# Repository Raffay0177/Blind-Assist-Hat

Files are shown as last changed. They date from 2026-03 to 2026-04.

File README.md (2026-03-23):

# 🧢 Blind Assist Hat (BAH)

Welcome to the **Blind Assist Hat** project! This project aims to create an affordable, smart wearable device designed to help visually impaired individuals navigate their surroundings, read text, and understand the environment around them.

The system uses a combination of ultrasonic sensors, a Raspberry Pi Camera, and OpenAI's GPT-4o Vision API to act as a pair of "digital eyes," controlled entirely via a tactile 4-button wrist pad.

---

## 🌟 Key Features

1. **Obstacle Detection:** Ultrasonic sensors on the front, left, and right gently warn the user via dynamic audio beeps if they are getting too close to an object.
2. **Scene Description:** The AI looks through the camera and verbally describes what is in front of the user (e.g., *"There is a park bench and a tree ahead."*).
3. **Text Reading:** Identifies and reads street signs, documents, or labels out loud.
4. **Navigation Mode:** Toggles continuous proximity sensing.

---

## 🛠️ System Architecture

### 1. The 'Brain' (Raspberry Pi)
A Raspberry Pi acts as the central hub, processing all hardware interrupts and routing API calls.

### 2. The 'Eyes' (Sensors & Camera)
- **Camera (CSI Port):** Captures high-res frames for the Vision AI.
- **Ultrasonics (HC-SR04):** Measures physical distances. *(Warning: Requires a voltage divider for the Echo pins to protect the Pi's 3.3V GPIO).*

### 3. The 'Remote' (Wrist Pad)
A 4-button tactile interface worn on the wrist:
- **Button 1:** Describe the scene.
- **Button 2:** Read text/signs.
- **Button 3:** Toggle Navigation Mode (Ultrasonic warnings).
- **Button 4:** Repeat the last spoken output.

### 4. The 'Voice' (Speaker)
Native synthesized speech (Text-to-Speech) pushed directly through the Pi's 3.5mm Jack or HDMI port. No external buzzer required!

---

## 📁 Project Structure

```text
BDH/
├── ai/                 # OpenAI Vision API routing and TTS handlers
├── config/             # Centralized settings and GPIO pin mappings
├── core/               # Main application loop, state handling, and button dispatchers
├── hardware/           # Hardware schematics, 3D printable STL/SCAD models
├── input/              # GPIO button interrupt logic
├── sensors/            # Ultrasonic distance algorithms and picamera2 wrappers
├── tests/              # End-to-end workflow suite for PC testing
├── .env.example        # Environment variable template
├── install.sh          # One-shot Raspberry Pi setup script
└── requirements.txt    # Current Python dependencies
```

---

## 🚀 Getting Started

If you are a builder or technician setting this up on a Raspberry Pi, follow these steps:

### 1. Hardware Assembly
Before booting, refer to the wiring guides in the `hardware/schematics/` folder. 
> **Important:** Follow `hardware/schematics/gpio_wiring.md` closely to ensure you don't fry your Raspberry Pi using the 5V ultrasonic sensors!

### 2. Software Installation
Run the one-shot setup script to install all system dependencies (like `espeak` and `libcamera`) and generate the Python virtual environment:
```bash
bash install.sh
```

### 3. Configuration
Copy the provided `.env.example` file to `.env`:
```bash
cp .env.example .env
```
Open `.env` and configure your API keys:
```env
OPENAI_API_KEY=sk-your-openai-api-key-here
OBSTACLE_WARN_DISTANCE_CM=100
```
*(You can also adjust the max warning distance for ultrasonic navigation mode here).*

### 4. Running the System
Activate your environment and start the core loop:
```bash
source venv/bin/activate
python -m core.main
```

---

## 💻 Cross-Platform Testing (Windows/Mac)
Don't have a Raspberry Pi handy? The codebase is designed to safely degrade when missing physical hardware.
You can run `python tests/test_end_to_end.py` on your Windows/Mac PC to simulate button presses and test the flow logs!

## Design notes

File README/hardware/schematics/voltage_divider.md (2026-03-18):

# ⚡ The Voltage Divider (Translating Voltages Safely)

## Why do we need this? (The Simple Explanation)

In the Blind Assist Hat, our distance sensors (the Ultrasonic HC-SR04 sensors) run on **5 Volts** of electricity.
However, the "Brain" (our Raspberry Pi computer) is very sensitive and can only handle **3.3 Volts**.

If the 5-volt sensor shouts its signal directly into the 3.3-volt brain, it will cause permanent electrical damage to the Raspberry Pi!

**Think of it like this:** The sensor is a megaphone, and the Raspberry Pi has very sensitive ears. We need to put a muffler between them so the Pi can hear the signal safely without getting hurt.

## How it works
To safely connect them, we use a simple **Voltage Divider**. This is just two tiny electrical resistors placed in the wire path. They "divide" the electrical pressure, scaling the 5V signal safely down to ~3.3V.

### How to build it for the "Echo" wire
*(You must do this for the 'Echo' wire of ALL THREE front/left/right sensors)*

1. Take the **Echo** wire coming directly from the Sensor.
2. Add a `1kΩ resistor` (Resistor 1).
3. After Resistor 1, the wire splits into two paths:
   - **Path A** goes straight into the correct Raspberry Pi GPIO Pin (e.g., Pin 24 for the front sensor).
   - **Path B** goes through a `2kΩ resistor` (Resistor 2) and then connects to the **Ground (GND)**.

By simply running the electricity through these resistors in a fork shape, the voltage drops to a safe level, and the Raspberry Pi reads the distance signal perfectly!

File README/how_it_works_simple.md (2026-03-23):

# 🎩 How the Hat Works (Explained for a 2-Year-Old!)

Imagine you have a magical talking hat! 🧙‍♂️✨

Here is what the hat has inside it:

### 1. The Brain 🧠 (Raspberry Pi)
Inside the hat is a tiny, smart computer. It thinks very fast and tells all the other parts what to do! It is the boss of the hat.

### 2. The Eyes 👀 (Camera & Sensors)
- **The Camera** looks at what is in front of you. It can see trees, people, and read signs!
- **The Bat Ears (Sensors)** send out invisible sound waves that bounce off walls. If a wall is too close, the ears hear the echo and secretly tell the Brain!

### 3. The Voice 🗣️ (Speaker)
The hat can talk to you! If the bat ears hear a wall getting super close, the hat uses its Voice to go *"BEEP BEEP!"* so you don't bump your head. If the camera sees a dog, the hat uses its Voice to say *"I see a dog!"*

### 4. The Magic Buttons 🖲️ (Wrist Pad)
You wear a cool bracelet with 4 big buttons. You press a button to ask the hat a question!
- **Press Button 1:** "Hat, what do you see right now?"
- **Press Button 2:** "Hat, can you read that sign for me?"
- **Press Button 3:** "Hat, turn on the bat ears so I don't bump into things!"
- **Press Button 4:** "Hat, can you say that one more time?"

---

## 🔄 How They Play Together!
When you press a **Magic Button**, the **Brain** wakes up! It asks the **Eyes** to take a quick peek. The Brain thinks about what the Eyes saw, and then it uses the **Voice** to whisper in your ear so you can walk safely and happily! 🚶‍♂️🎉

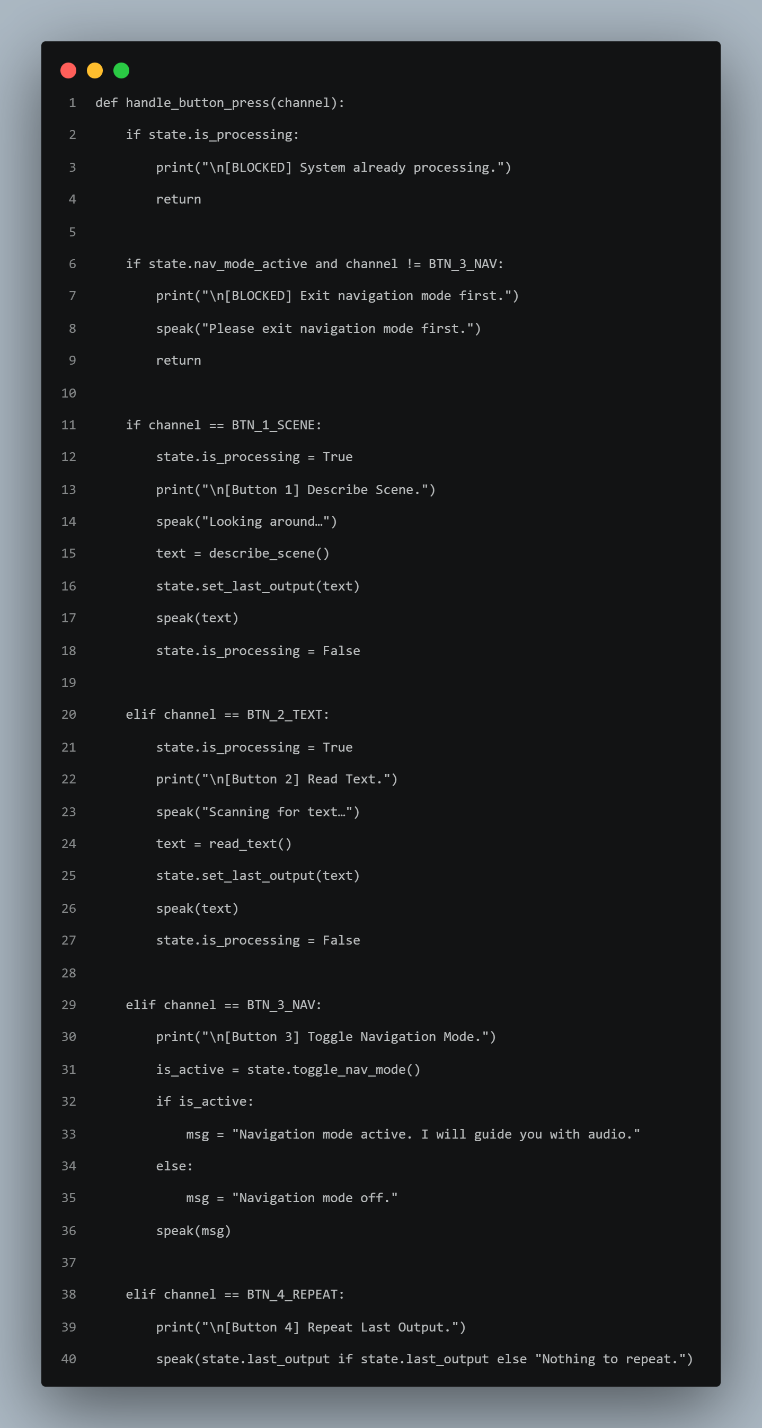
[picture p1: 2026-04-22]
README/hardware/schematics/Code Pictures/button_logic.png

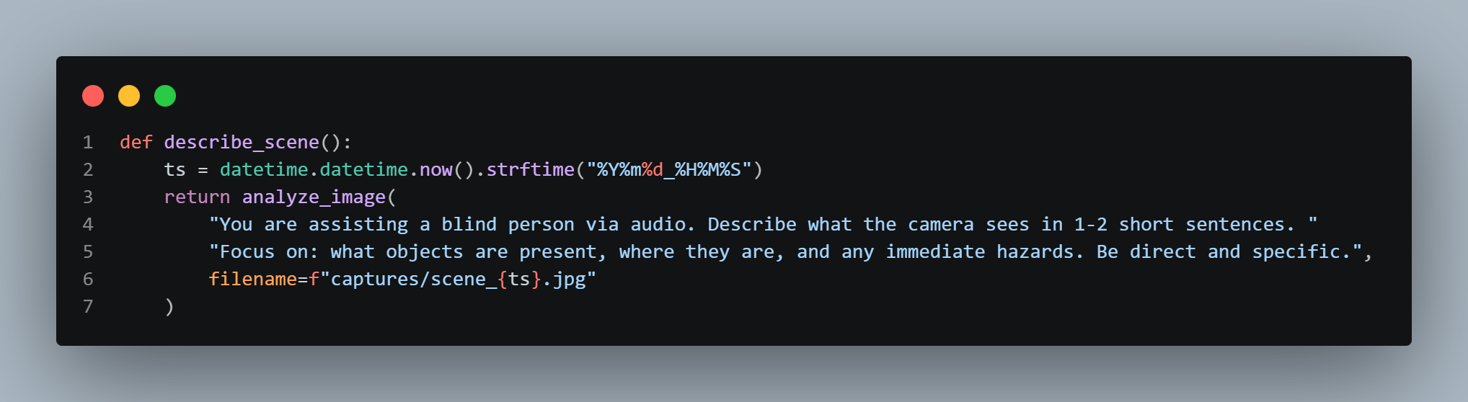
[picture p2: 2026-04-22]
README/hardware/schematics/Code Pictures/describe_scene.png

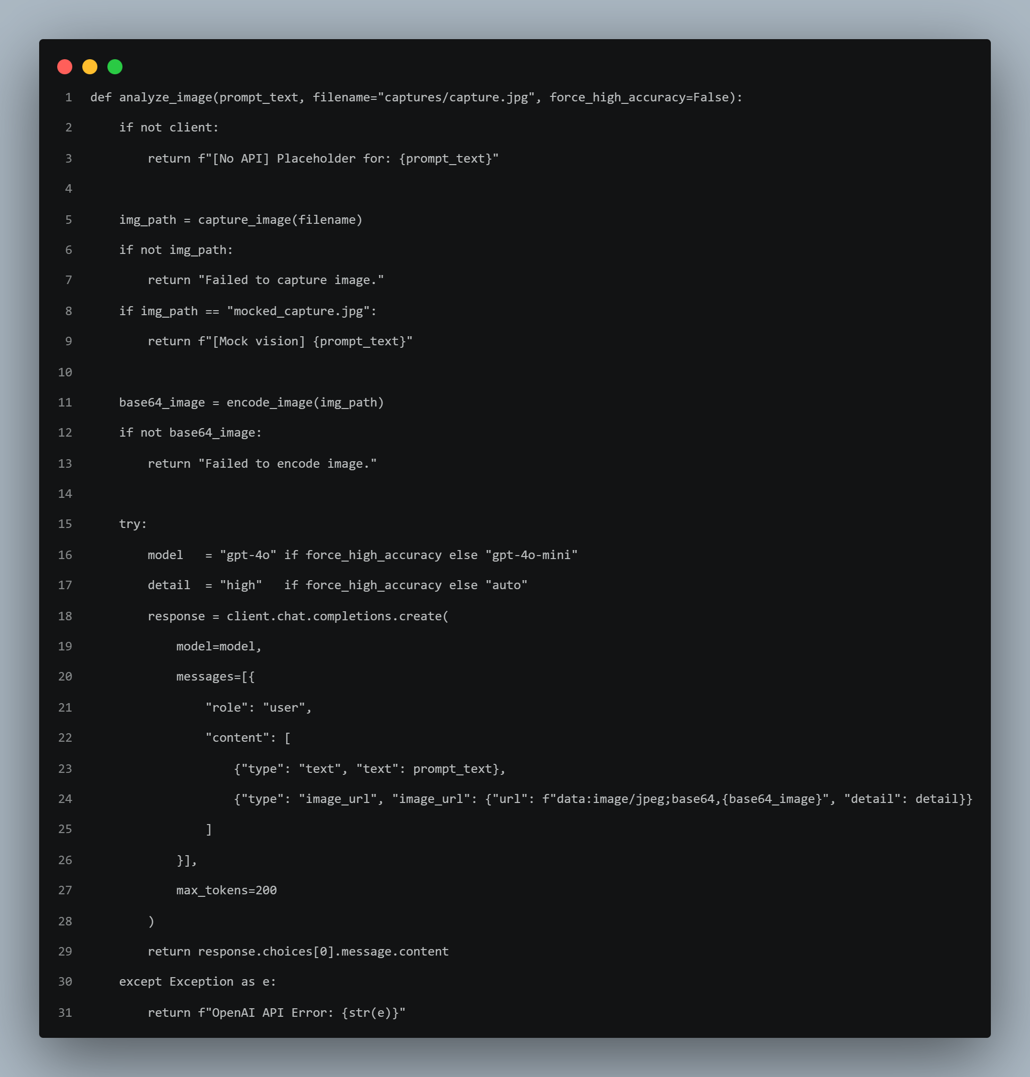
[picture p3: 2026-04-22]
README/hardware/schematics/Code Pictures/analyze_image.png

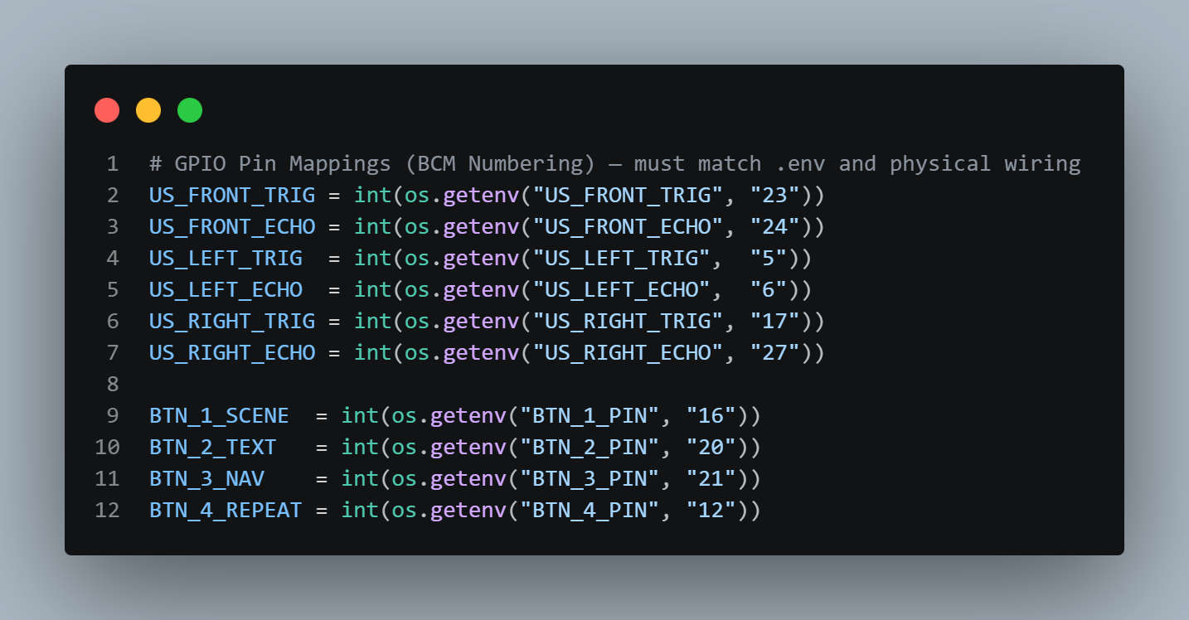
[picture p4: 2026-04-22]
README/hardware/schematics/Code Pictures/GPIO pin mappings.png

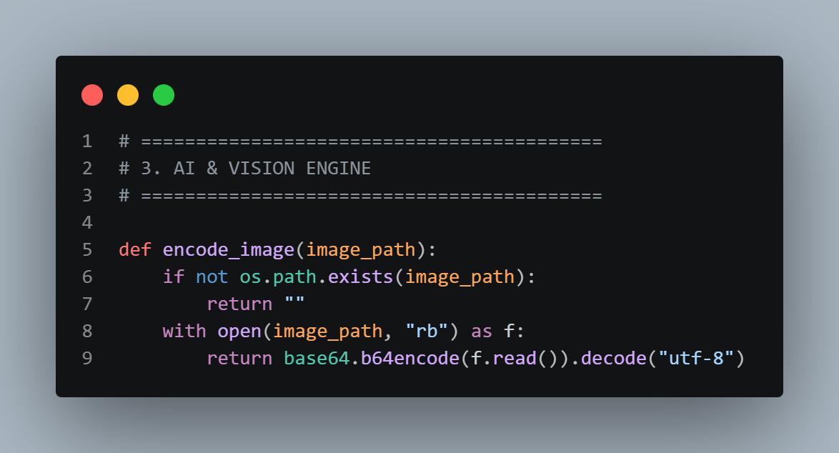
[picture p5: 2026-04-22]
README/hardware/schematics/Code Pictures/image_encode.png

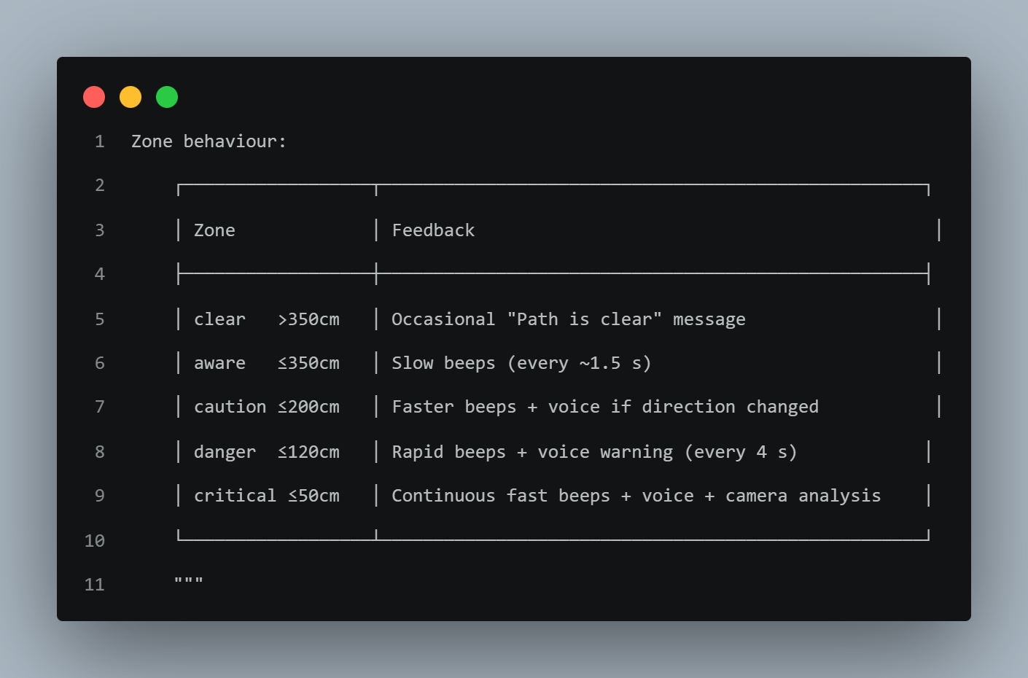
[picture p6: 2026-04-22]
README/hardware/schematics/Code Pictures/nav_settings.png

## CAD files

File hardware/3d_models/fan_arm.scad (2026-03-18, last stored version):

// OpenSCAD: single fan arm (print x4)

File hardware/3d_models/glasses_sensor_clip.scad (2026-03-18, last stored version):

// OpenSCAD: glasses sensor clip

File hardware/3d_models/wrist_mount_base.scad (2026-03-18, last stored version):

// OpenSCAD: wrist sleeve base

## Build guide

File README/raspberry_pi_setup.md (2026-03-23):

# 🍓 Raspberry Pi Complete Setup Guide

Follow this step-by-step guide to get the Blind Assist Hat running from scratch on a new Raspberry Pi.

## 1. Hardware Preparation
Before turning on the Raspberry Pi, ensure all physical components are connected correctly.
- **Camera:** Connect the ribbon cable to the CSI port.
- **Speaker:** Plug your speaker or headphones into the 3.5mm audio jack.
- **Ultrasonic Sensors & Buttons:** Carefully wire these to the GPIO pins. 
  > ⚠️ **CRITICAL:** Ensure you use a voltage divider on the Ultrasonic *Echo* pins so you don't send 5V into the Pi's 3.3V GPIO pins! 
  *(Detailed pin map: `hardware/schematics/gpio_wiring.md`)*

## 2. Raspberry Pi OS Setup
1. Use the **Raspberry Pi Imager** to flash an SD card with **Raspberry Pi OS (64-bit)**.
2. Ensure you enable Wi-Fi and SSH in the advanced settings of the imager so it automatically connects to your network.
3. Insert the SD card, power on the Pi, and either connect it to a monitor/keyboard or SSH into it from your computer.

## 3. Clone the Project
Open the Raspberry Pi's terminal and download the code from your GitHub repository:
```bash
git clone https://github.com/Raffay0177/Blind-Assist-Hat.git
cd Blind-Assist-Hat
```

## 4. Run the Automated Installer
The repository includes a script that automatically updates your system and installs all necessary dependencies (like `espeak`, `picamera2`, `openai`, and `Python Virtual Environments`).

Run this command:
```bash
bash install.sh
```
*(This may take a few minutes depending on your internet connection).*

## 5. Configure Your Keys
The AI Vision mapping requires an OpenAI API key.

1. Once the installer finishes, copy the template `.env` file to create your local copy:
   ```bash
   cp .env.example .env
   ```
2. Open the file to edit it:
   ```bash
   nano .env
   ```
3. Find the line `OPENAI_API_KEY=...` and replace the placeholder with your actual OpenAI key.
4. Save and exit (Press `Ctrl+O`, hit `Enter`, then press `Ctrl+X`).

## 6. Run the Software!
Activate your virtual environment (where the installer put all the Python libraries) and boot up the core system:
```bash
source venv/bin/activate
python -m core.main
```

You should hear the script launch, and the system is now ready to respond to your wrist button presses! 🎉

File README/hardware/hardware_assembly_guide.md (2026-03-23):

# 🔧 Step-by-Step Hardware Assembly Guide

Welcome to the wiring portion of the Blind Assist Hat! This process is simple.

---

## Step 1: Connecting the Camera & Speaker
1. **The Camera**: Insert the camera ribbon cable straight into the `CSI` port.
2. **The Speaker**: Plug directly into the Raspberry Pi's **3.5mm audio jack**.

---

## Step 2: Wiring the Wrist Buttons
Connect each button bridging between a GPIO pin and Ground.

```mermaid
flowchart LR
    subgraph Raspberry Pi
        P_16[GPIO 16]
        P_20[GPIO 20]
        P_21[GPIO 21]
        P_12[GPIO 12]
        P_GND[Any GND Pin]
    end

    subgraph Wrist Pad
        B1((Button 1))
        B2((Button 2))
        B3((Button 3))
        B4((Button 4))
    end
    
    B1 -->|Leg 1| P_16
    B1 -->|Leg 2| P_GND

    B2 -->|Leg 1| P_20
    B2 -->|Leg 2| P_GND

    B3 -->|Leg 1| P_21
    B3 -->|Leg 2| P_GND

    B4 -->|Leg 1| P_12
    B4 -->|Leg 2| P_GND
```

---

## Step 3: Wiring the Ultrasonic Sensors

Since your specific HC-SR04 sensors are compatible with **3.3 Volts**, they can wire perfectly directly to the Raspberry Pi without any external voltage dividers!

### Ultrasonic Sensor Front Connections
| Pin | Connection |
| :--- | :--- |
| VCC | 3.3V |
| Trig | GPIO 23 |
| Echo | GPIO 24 |
| GND | GND |

### Ultrasonic Sensor Left Connections
| Pin | Connection |
| :--- | :--- |
| VCC | 3.3V |
| Trig | GPIO 17 |
| Echo | GPIO 27 |
| GND | GND |

### Ultrasonic Sensor Right Connections
| Pin | Connection |
| :--- | :--- |
| VCC | 3.3V |
| Trig | GPIO 5 |
| Echo | GPIO 6 |
| GND | GND |

### Diagram Example (Front Sensor)
```mermaid
flowchart LR
    subgraph Raspberry Pi
        P_3_3V[3.3V Pin]
        P_GND[GND Pin]
        P_23[GPIO 23]
        P_24[GPIO 24]
    end

    subgraph Front Sensor
        VCC
        TRIG
        ECHO
        GND
    end

    P_3_3V --> VCC
    P_GND --> GND
    P_23 --> TRIG
    ECHO --> P_24
```

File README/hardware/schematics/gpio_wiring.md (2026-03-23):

# Hardware Connection Guide (Raspberry Pi)

## Ultrasonic Sensors

### Ultrasonic Sensor Front Connections
| Pin | Connection |
| :--- | :--- |
| VCC | 3.3V |
| Trig | GPIO 23 |
| Echo | GPIO 24 |
| GND | GND |

### Ultrasonic Sensor Left Connections
| Pin | Connection |
| :--- | :--- |
| VCC | 3.3V |
| Trig | GPIO 17 |
| Echo | GPIO 27 |
| GND | GND |

### Ultrasonic Sensor Right Connections
| Pin | Connection |
| :--- | :--- |
| VCC | 3.3V |
| Trig | GPIO 5 |
| Echo | GPIO 6 |
| GND | GND |

---

## Wrist Button Pad Connections

| Button | Connection |
| :--- | :--- |
| **Button 1** (Describe Scene) | GPIO 16 to GND |
| **Button 2** (Read Text) | GPIO 20 to GND |
| **Button 3** (Toggle Nav Mode) | GPIO 21 to GND |
| **Button 4** (Repeat Last) | GPIO 12 to GND |

---

## Speaker & Camera Connections
- **Speaker**: Direct to 3.5mm Audio Jack.
- **Camera**: Ribbon cable direct to Raspberry Pi CSI Port.

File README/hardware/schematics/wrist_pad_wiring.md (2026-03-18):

# ⌚ The Wrist Pad Wiring Guide

The wrist pad serves as the "Remote Control" for the Blind Assist Hat. Because visually impaired users need a reliable and tactile way to control the AI, we use four physical push-buttons mounted on a wrist strap.

## How do the buttons work?
When a user presses a button down, it connects two pieces of metal inside the button switch. This closes an electrical loop, allowing a tiny bit of electricity to flow into the Raspberry Pi's "GPIO Pin". The Pi instantly senses this flow and triggers the Voice AI or Camera to act.

## Physical Wiring
Each button has two metal legs underneath it.

1. **Leg 1:** Connects to the specific GPIO Pin (see below).
2. **Leg 2:** Connects to the **Ground (GND)** on the Raspberry Pi.

*(For efficiency, you can daisy-chain all four Button Leg 2s together and run just one single Ground wire back to the Raspberry Pi).*

## The Map

| Location on Wrist | Button | Connect Leg 1 to... | Function for the User |
|---|---|---|---|
| Top Left | **B1** | `GPIO Pin 16` | Describe surroundings |
| Top Right | **B2** | `GPIO Pin 20` | Read text out loud |
| Bottom Left | **B3** | `GPIO Pin 21` | Start Navigation |
| Bottom Right | **B4** | `GPIO Pin 12` | Repeat last output |

## Tips for the Assembly Team
- Ensure the buttons have a satisfying "click" so the user can feel that they pressed it successfully.
- The wires connecting the wrist pad to the hat should run down the user’s sleeve, so make sure they are flexible and reinforced so they don't break during arm movements.

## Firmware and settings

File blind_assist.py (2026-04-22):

#!/usr/bin/env python3
"""
Blind Assist Hat — Core Application
Runs on Raspberry Pi with HC-SR04 ultrasonic sensors, CSI/USB camera,
GPIO push-buttons, and OpenAI APIs for vision + TTS.
"""

import os
import sys
import time
import base64
import threading
import subprocess
import shutil
import datetime
import pyaudio
import numpy as np

# Try to import dotenv for environment variables
try:
    from dotenv import load_dotenv
    load_dotenv()
except ImportError:
    print("WARN: python-dotenv not installed. Reading env vars directly.")

# ==========================================
# CONFIGURATION & ENVIRONMENT
# ==========================================

OPENAI_API_KEY = os.getenv("OPENAI_API_KEY", "")

# OpenAI TTS settings — voice options: alloy, echo, fable, onyx, nova, shimmer
# "nova" is warm and natural; "shimmer" is expressive and clear for guidance.
TTS_VOICE     = os.getenv("TTS_VOICE_NAME", "nova")          # OpenAI voice name
TTS_MODEL     = os.getenv("TTS_MODEL",      "tts-1-hd")      # tts-1 or tts-1-hd

# Navigation distance thresholds (cm)
# HC-SR04 reliable range: ~2 cm – 400 cm
# Tuned for typical indoor room environments (tighter than outdoor defaults)
ZONE_CRITICAL  = int(os.getenv("ZONE_CRITICAL_CM",  "40"))   # Imminent — stop now
ZONE_DANGER    = int(os.getenv("ZONE_DANGER_CM",    "90"))   # Very close — act now
ZONE_CAUTION   = int(os.getenv("ZONE_CAUTION_CM",  "160"))   # Approaching — heads up
ZONE_AWARE     = int(os.getenv("ZONE_AWARE_CM",    "280"))   # Environmental awareness

# Clear-path announcement cooldown (seconds)
# Increased to avoid spamming "path is clear" in open spaces
CLEAR_PATH_COOLDOWN = float(os.getenv("CLEAR_PATH_COOLDOWN", "12.0"))

# ==========================================
# OPENAI CLIENT
# ==========================================

try:
    from openai import OpenAI
    client = OpenAI(api_key=OPENAI_API_KEY) if OPENAI_API_KEY else None
except ImportError:
    print("WARN: openai package not installed.")
    client = None

# ==========================================
# CAMERA
# ==========================================

try:
    from picamera2 import Picamera2  # type: ignore
    csi_available = True
except ImportError:
    csi_available = False

# ==========================================
# GPIO
# ==========================================

try:
    import RPi.GPIO as GPIO  # type: ignore
    hardware_available = True
except ImportError:
    print("WARN: RPi.GPIO not found — running in MOCK mode.")
    from unittest.mock import MagicMock
    GPIO = MagicMock()
    sys.modules['RPi']     = MagicMock()
    sys.modules['RPi.GPIO'] = GPIO
    hardware_available = False

# GPIO Pin Mappings (BCM Numbering) — must match .env and physical wiring
US_FRONT_TRIG = int(os.getenv("US_FRONT_TRIG", "23"))
US_FRONT_ECHO = int(os.getenv("US_FRONT_ECHO", "24"))
US_LEFT_TRIG  = int(os.getenv("US_LEFT_TRIG",  "5"))
US_LEFT_ECHO  = int(os.getenv("US_LEFT_ECHO",  "6"))
US_RIGHT_TRIG = int(os.getenv("US_RIGHT_TRIG", "17"))
US_RIGHT_ECHO = int(os.getenv("US_RIGHT_ECHO", "27"))

BTN_1_SCENE  = int(os.getenv("BTN_1_PIN", "16"))
BTN_2_TEXT   = int(os.getenv("BTN_2_PIN", "20"))
BTN_3_NAV    = int(os.getenv("BTN_3_PIN", "21"))
BTN_4_REPEAT = int(os.getenv("BTN_4_PIN", "12"))

# ==========================================
# 1. STATE MANAGEMENT
# ==========================================

class AppState:
    def __init__(self):
        self.nav_mode_active    = False
        self.last_output        = ""
        self.is_speaking        = False
        self.is_processing      = False

    def toggle_nav_mode(self):
        self.nav_mode_active = not self.nav_mode_active
        return self.nav_mode_active

    def set_last_output(self, text):
        self.last_output = text

state = AppState()

# ==========================================
# 2. CAMERA MODULE
# ==========================================

def capture_image(filename="capture.jpg"):
    """
    Captures an image:
    1. CSI Camera (Picamera2) — preferred
    2. USB Camera (fswebcam)  — fallback
    3. Mock                   — development fallback
    """
    capture_dir = os.path.join(os.path.dirname(os.path.abspath(__file__)), "captures")
    os.makedirs(capture_dir, exist_ok=True)
    filepath = os.path.join(os.path.dirname(os.path.abspath(__file__)), filename)

    if csi_available:
        try:
            picam2 = Picamera2()
            cfg = picam2.create_preview_configuration(main={"size": (1280, 720)})
            picam2.configure(cfg)
            picam2.start()
            time.sleep(1.0)   # sensor warm-up
            picam2.capture_file(filepath)
            picam2.stop()
            picam2.close()
            return filepath
        except Exception as e:
            print(f"DEBUG: CSI Camera (Picamera2) failed: {e}")

    if shutil.which("fswebcam"):
        try:
            print("📸 [USB CAMERA] Using fswebcam.")
            subprocess.run(
                ["fswebcam", "-r", "1280x720", "-S", "20", "--no-banner", filepath],
                check=True, capture_output=True
            )
            return filepath
        except Exception as e:
            print(f"DEBUG: USB Camera (fswebcam) failed: {e}")

    print("📸 [MOCK CAMERA] Simulated capture.")
    return "mocked_capture.jpg"

# ==========================================
# 3. AI & VISION ENGINE
# ==========================================

def encode_image(image_path):
    if not os.path.exists(image_path):
        return ""
    with open(image_path, "rb") as f:
        return base64.b64encode(f.read()).decode("utf-8")

def analyze_image(prompt_text, filename="captures/capture.jpg", force_high_accuracy=False):
    if not client:
        return f"[No API] Placeholder for: {prompt_text}"

    img_path = capture_image(filename)
    if not img_path:
        return "Failed to capture image."
    if img_path == "mocked_capture.jpg":
        return f"[Mock vision] {prompt_text}"

    base64_image = encode_image(img_path)
    if not base64_image:
        return "Failed to encode image."

    try:
        model   = "gpt-4o" if force_high_accuracy else "gpt-4o-mini"
        detail  = "high"   if force_high_accuracy else "auto"
        response = client.chat.completions.create(
            model=model,
            messages=[{
                "role": "user",
                "content": [
                    {"type": "text", "text": prompt_text},
                    {"type": "image_url", "image_url": {"url": f"data:image/jpeg;base64,{base64_image}", "detail": detail}}
                ]
            }],
            max_tokens=200
        )
        return response.choices[0].message.content
    except Exception as e:
        return f"OpenAI API Error: {str(e)}"

def describe_scene():
    ts = datetime.datetime.now().strftime("%Y%m%d_%H%M%S")
    return analyze_image(
        "You are assisting a blind person via audio. Describe what the camera sees in 1-2 short sentences. "
        "Focus on: what objects are present, where they are, and any immediate hazards. Be direct and specific.",
        filename=f"captures/scene_{ts}.jpg"
    )

def read_text():
    ts = datetime.datetime.now().strftime("%Y%m%d_%H%M%S")
    return analyze_image(
        "I am a vision assistant for the blind. Identify any text, signs, labels, or handwriting in this image. "
        "Read the text exactly as it appears, left to right, top to bottom. If no text is visible, say 'No text detected'.",
        filename=f"captures/text_{ts}.jpg",
        force_high_accuracy=True
    )

def analyze_collision():
    ts = datetime.datetime.now().strftime("%Y%m%d_%H%M%S")
    return analyze_image(
        "A blind user is about to collide with an object straight ahead. "
        "Identify the object in 1-3 words, and give one very short avoidance instruction. "
        "Example: 'Chair. Step right.'",
        filename=f"captures/collision_{ts}.jpg"
    )

# ==========================================
# 4. TEXT-TO-SPEECH  (OpenAI TTS-HD)
# ==========================================

_tts_lock = threading.Lock()

def speak(text):
    """
    Primary TTS: OpenAI tts-1-hd with natural voice (nova by default).
    Fallback: espeak for offline / no-API scenarios.
    Thread-safe via lock to prevent audio overlap.
    """
    if not text:
        return
    print(f"🔊 [TTS]: {text}")
    with _tts_lock:
        state.is_speaking = True
        if client:
            _openai_tts(text)
        else:
            _fallback_espeak(text)
        state.is_speaking = False

def _openai_tts(text):
    audio_file = "/tmp/bah_speech.mp3"
    try:
        response = client.audio.speech.create(
            model=TTS_MODEL,      # tts-1-hd for highest quality
            voice=TTS_VOICE,      # nova — warm, natural, clear for guidance
            input=text,
            response_format="mp3"
        )
        response.write_to_file(audio_file)
        # Use mpg123 if available (better mp3 support), else ffplay, else aplay with wav
        if shutil.which("mpg123"):
            subprocess.run(["mpg123", "-q", audio_file], check=False)
        elif shutil.which("ffplay"):
            subprocess.run(["ffplay", "-nodisp", "-autoexit", "-loglevel", "quiet", audio_file], check=False)
        else:
            # Last resort: convert mp3 → wav and play with aplay
            wav_file = "/tmp/bah_speech.wav"
            subprocess.run(["ffmpeg", "-y", "-i", audio_file, wav_file], capture_output=True, check=False)
            subprocess.run(["aplay", "-q", wav_file], check=False)
    except Exception as e:
        print(f"DEBUG: OpenAI TTS failed ({e}), falling back to espeak.")
        _fallback_espeak(text)

def _fallback_espeak(text):
    """Offline TTS fallback using espeak."""
    try:
        clean = text.replace('"', '').replace("'", "")
        subprocess.run(["espeak", "-s", "140", clean], check=False, capture_output=True)
    except FileNotFoundError:
        print("WARN: espeak not found. No audio output.")

# ==========================================
# 5. NAVIGATION & AUDIO BEEP SYSTEM
# ==========================================

# PyAudio instance (shared)
try:
    _pa = pyaudio.PyAudio()
except Exception:
    _pa = None

def nav_setup():
    """Configure GPIO pins for all three HC-SR04 ultrasonic sensors."""
    GPIO.setmode(GPIO.BCM)
    for trig, echo in [
        (US_FRONT_TRIG, US_FRONT_ECHO),
        (US_LEFT_TRIG,  US_LEFT_ECHO),
        (US_RIGHT_TRIG, US_RIGHT_ECHO),
    ]:
        GPIO.setup(trig, GPIO.OUT)
        GPIO.setup(echo, GPIO.IN)

# HC-SR04 physically cannot detect closer than ~2 cm.
# Any reading below this is electrical noise — treat as invalid.
_MIN_VALID_CM = 2.0

def _read_distance(trig_pin, echo_pin, timeout_s=0.04):
    """
    Read distance from a single HC-SR04 sensor.
    Returns distance in centimetres, or 999 on timeout/error.

    FIX: TRIG is held LOW for 5µs (not 2µs) before pulsing — this fully
    resets the pin and prevents false triggers from residual charge.
    """
    try:
        # Hold TRIG LOW long enough to clear any residual signal
        GPIO.output(trig_pin, 0)
        time.sleep(0.000005)          # 5µs LOW — was 2µs, fixes false triggers
        GPIO.output(trig_pin, 1)
        time.sleep(0.00001)           # 10µs HIGH pulse to trigger sensor
        GPIO.output(trig_pin, 0)

        deadline = time.time() + timeout_s

        # Wait for ECHO to go HIGH (sensor detected pulse going out)
        while GPIO.input(echo_pin) == 0:
            if time.time() > deadline:
                return 999.0          # timeout = nothing detected
        t_start = time.time()

        # Wait for ECHO to go LOW (reflected pulse received back)
        while GPIO.input(echo_pin) == 1:
            if time.time() > deadline:
                return 999.0
        t_end = time.time()

        dist = (t_end - t_start) * 340 * 100 / 2  # speed of sound → cm

        # Reject physically impossible readings (noise / ringing artefact)
        if dist < _MIN_VALID_CM:
            return 999.0
        return dist
    except Exception:
        return 999.0

# Label used to identify sensor in terminal debug output
_SENSOR_LABELS = {}

def _read_distance_avg(trig_pin, echo_pin, samples=5, label=""):
    """
    Average multiple readings to reduce sensor noise.
    Drops the single highest AND lowest reading (trimmed mean) to
    reject both reflection spikes and false-short noise pulses.
    Prints every raw sample to terminal so you can see exactly what
    the sensor is reporting in real time.
    """
    readings = []
    raw_log = []
    for i in range(samples):
        d = _read_distance(trig_pin, echo_pin)
        raw = f"{d:6.1f}" if d < 999.0 else " NONE "
        raw_log.append(raw)
        if d < 999.0:
            readings.append(d)
        time.sleep(0.012)             # 12ms between samples — HC-SR04 settling time

    # Print every raw sample so you can see sensor behaviour live
    print(f"  [{label:5s}] raw: {' | '.join(raw_log)}")

    if not readings:
        return 999.0
    # Trimmed mean: drop highest AND lowest to filter outliers in both directions
    if len(readings) > 3:
        readings.remove(max(readings))
        readings.remove(min(readings))
    elif len(readings) > 2:
        readings.remove(max(readings))  # at least drop the high spike
    avg = sum(readings) / len(readings)
    print(f"  [{label:5s}] avg: {avg:6.1f} cm  zone={_zone_label(avg).upper()}")
    return avg

def _zone_label(dist_cm):
    """Return a human-readable proximity zone for a distance."""
    if dist_cm <= ZONE_CRITICAL:  return "critical"
    if dist_cm <= ZONE_DANGER:    return "danger"
    if dist_cm <= ZONE_CAUTION:   return "caution"
    if dist_cm <= ZONE_AWARE:     return "aware"
    return "clear"

def play_beep(duration_sec, frequency=800, volume=0.85):
    """Synthesise and play a short beep tone via PyAudio."""
    if not _pa:
        return
    sample_rate = 44100
    n = int(sample_rate * duration_sec)
    t = np.linspace(0, duration_sec, n, False)
    tone = np.sin(frequency * t * 2 * np.pi) * volume
    # Smooth fade-in / fade-out to prevent clicks
    fade = min(int(sample_rate * 0.008), n // 2)
    tone[:fade]  *= np.linspace(0, 1, fade)
    tone[-fade:] *= np.linspace(1, 0, fade)
    audio_data = (tone * 32767).astype(np.int16).tobytes()
    try:
        stream = _pa.open(format=pyaudio.paInt16, channels=1, rate=sample_rate, output=True)
        stream.write(audio_data)
        stream.stop_stream()
        stream.close()
    except Exception:
        pass

# ── Navigation state ──────────────────────────────────────────────────────────
_nav_last_spoken_time       = 0.0
_nav_last_direction         = ""
_nav_last_zone              = "clear"
_nav_last_clear_spoken_time = 0.0
_nav_last_vision_time       = 0.0

def _classify_scene(front, left, right):
    """
    Decide what voice cue (if any) to give based on all three sensor readings.
    Returns (message_or_None, beep_freq_or_None).
    Voice cues take priority over beeps.
    """
    f_zone = _zone_label(front)
    l_zone = _zone_label(left)
    r_zone = _zone_label(right)

    # Build a composite spoken warning
    warnings = []

    # Front sensor drives primary messaging
    if f_zone == "critical":
        warnings.append("Stop! Obstacle straight ahead")
    elif f_zone == "danger":
        warnings.append("Obstacle ahead")
    elif f_zone == "caution":
        warnings.append("Caution ahead")

    # Add side context if meaningful
    if l_zone in ("critical", "danger") and r_zone not in ("critical", "danger"):
        warnings.append("and to your left")
    elif r_zone in ("critical", "danger") and l_zone not in ("critical", "danger"):
        warnings.append("and to your right")
    elif l_zone in ("critical", "danger") and r_zone in ("critical", "danger"):
        warnings.append("on both sides")

    # If only side obstacles exist (front is clear)
    if not warnings:
        if l_zone in ("critical", "danger"):
            warnings.append("Obstacle on your left")
        if r_zone in ("critical", "danger"):
            warnings.append("Obstacle on your right")

    # Compose message
    message = " ".join(warnings) + ("." if warnings else "")

    # Determine beep frequency to accompany or replace voice
    # Lower pitch = left, Mid = front, Higher = right
    min_dist = min(front, left, right)
    if min_dist == left:
        freq = 450
    elif min_dist == front:
        freq = 850
    else:
        freq = 1200

    return (message if warnings else None), freq, min_dist

def collision_warning_routine():
    """
    Triggered on imminent/critical front obstacle.
    AUTO SCENE DESCRIBE DISABLED — camera AI analysis removed because:
      - It adds 1-3s latency at the worst possible moment
      - The user needs an instant reaction, not a wait
      - Use Button 1 manually to get a scene description instead
    Now just fires an immediate urgent voice warning.
    """
    state.is_processing = True
    speak("Stop! Obstacle directly ahead.")
    state.is_processing = False
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

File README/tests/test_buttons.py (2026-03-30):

"""
test_buttons.py
A simple script to test if the physical buttons are communicating with the Raspberry Pi.
Uses gpiozero, which is the modern standard for Raspberry Pi hardware control.
Run: python3 test_buttons.py
"""

import sys

try:
    from gpiozero import Button
    from signal import pause
except ImportError:
    print("[ERROR] gpiozero not installed. This script must be run on a Raspberry Pi.")
    print("        You can install it with: sudo apt install python3-gpiozero")
    sys.exit(1)

# Hardcoded pin mappings for easy testing and modification
BTN_1_SCENE = 16
BTN_2_TEXT = 20
BTN_3_NAV = 21
BTN_4_REPEAT = 12

def on_button_1_pressed():
    print("\n[OK] Detected Press on Button 1 (Describe Scene) (GPIO 16)")

def on_button_2_pressed():
    print("\n[OK] Detected Press on Button 2 (Read Text) (GPIO 20)")

def on_button_3_pressed():
    print("\n[OK] Detected Press on Button 3 (Toggle Nav Mode) (GPIO 21)")

def on_button_4_pressed():
    print("\n[OK] Detected Press on Button 4 (Repeat Last) (GPIO 12)")

def main():
    print("=" * 50)
    print("  Blind Assist Hat – GPIOZero Button Test")
    print("=" * 50)
    print("This script uses 'gpiozero' to verify if your buttons are wired correctly.")
    print("Press Ctrl+C to exit.\n")

    # gpiozero automatically handles debouncing (bounce_time) and internal pull-ups!
    # By default, Button assumes the button connects to GND (pull_up=True).
    print("Initializing GPIO 16...")
    btn1 = Button(BTN_1_SCENE, bounce_time=0.1)
    btn1.when_pressed = on_button_1_pressed
    
    print("Initializing GPIO 20...")
    btn2 = Button(BTN_2_TEXT, bounce_time=0.1)
    btn2.when_pressed = on_button_2_pressed
    
    print("Initializing GPIO 21...")
    btn3 = Button(BTN_3_NAV, bounce_time=0.1)
    btn3.when_pressed = on_button_3_pressed
    
    print("Initializing GPIO 12...")
    btn4 = Button(BTN_4_REPEAT, bounce_time=0.1)
    btn4.when_pressed = on_button_4_pressed

    print("\nReady! Press any button on the wrist pad now...")
    
    try:
        pause()  # This keeps the script running silently while waiting for interrupts
    except KeyboardInterrupt:
        print("\nExiting test. GPIO cleaned up automatically. Goodbye!")

if __name__ == "__main__":
    main()

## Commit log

2026-03-18 Initial structure for Blind Assist Hat
    [fan_arm.scad, glasses_sensor_clip.scad, wrist_mount_base.scad]
2026-03-23 Complete project integration: AI, Sensors, and Documentation
2026-03-23 Add Raspberry Pi Complete Setup Guide
2026-03-23 docs: add visual step-by-step assembly guide with mermaid diagrams
2026-03-23 docs: reformat hardware schematics mapping to 3.3V ultrasonic tables
2026-03-25 Add USB camera support and hardware test scripts
2026-03-25 Add keyboard input support (1-4) as fallback for buttons
2026-03-25 Improve OCR prompt and USB camera quality
2026-03-30 Add polling fallback for edge detection errors
    [test_buttons.py]
2026-03-30 Add button lockout feature and fix nav mode hardware bouncing
2026-03-30 Mute sonar beeps during TTS playback to prevent audio overlap
2026-04-01 Change navigation voice cue threshold to 40cm
2026-04-08 feat: Add startup battery and speaker announcement
2026-04-08 Revert "feat: Add startup battery and speaker announcement"
    This reverts commit 1cb3d8f085806a75520b4228ee01e2a496265825.
2026-04-08 feat: Save all camera captures to captures directory
2026-04-08 fix: Swap left/right ultrasonic pins to match hardware
2026-04-08 fix: Add processing lock to prevent button bounce queuing
2026-04-15 Final: Consolidate modular structure into blind_assist.py and clean up project
    [fan_arm.scad, glasses_sensor_clip.scad, wrist_mount_base.scad]
2026-04-15 feat: OpenAI HD TTS voice, real-world nav zones, RPi deployment fixes
    - TTS: upgrade to tts-1-hd model with 'nova' voice (natural, warm)
    - mpg123/ffplay/aplay fallback chain for MP3 playback
    - Voice name configurable via TTS_VOICE_NAME env var
    - Nav: 4-zone proximity system tuned for real indoor room scale
    - Clear >350cm: periodic 'path is clear' announcement
    - Aware <=350cm: slow beeps only
    - Caution <=200cm: faster beeps + directional voice cues
    - Danger <=120cm: rapid beeps + voice every 4s
    - Critical <=50cm: max beeps + camera collision analysis
    - Side-context messages ('ahead and to your left', 'both sides')
    - 3-sample sensor averaging to reduce noise
    - Linear beep r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
    [blind_assist.py]
2026-04-15 fix: reduce button bounce_time 300ms -> 50ms for instant tap registration
    [blind_assist.py]
2026-04-22 Disable auto collision scene describe; fine-tune ultrasonic sensor zones and beep feedback for indoor use
    [blind_assist.py]
2026-04-22 Fix sensor crosstalk (60ms inter-sensor gap), false critical (2cm floor + trimmed mean filter), stronger TRIG reset
    [blind_assist.py]
2026-04-22 Fix direction detection (float == bug), raise inter-sensor gap to 100ms, add per-sample verbose terminal output
    [blind_assist.py]
2026-04-22 Sync latest project structure: add README and batch files folders, remove old loose files
    [test_api_key.py, test_beeps.py, test_buttons.py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]
